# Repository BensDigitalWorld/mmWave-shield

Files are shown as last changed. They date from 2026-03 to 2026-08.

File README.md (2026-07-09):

<p align="center">
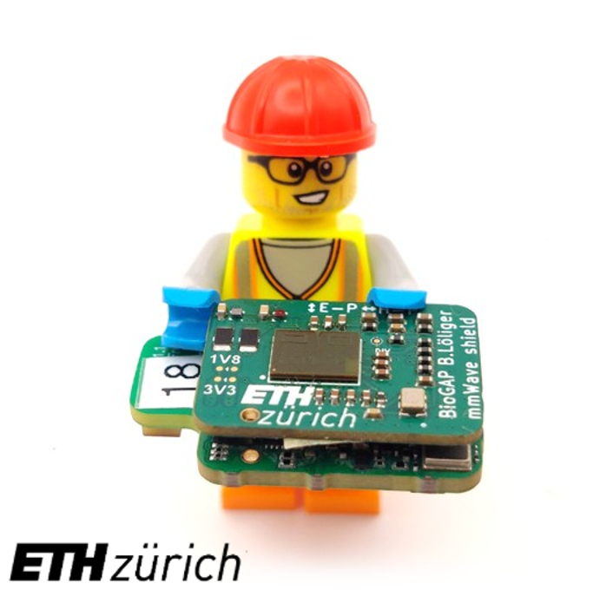
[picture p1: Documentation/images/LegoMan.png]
Device showcase
  
</p>

# mmWave-shield

## Wearable mmWave Sensor, for BP measurments. Shield for the BioGap9 Platform 

## Introduction

This repository contains the hardware, firmware, and software developed for a wearable mmWave radar sensing prototype based on the BioGAP platform.

The project integrates a custom BGT60TR13C mmWave radar shield with the BioGAP firmware and provides Python tools for data acquisition, live visualization, offline signal processing, and validation measurements.

The system was developed as a research prototype for contactless pulse-wave sensing using a wearable mmWave radar sensor.

<p align="center">
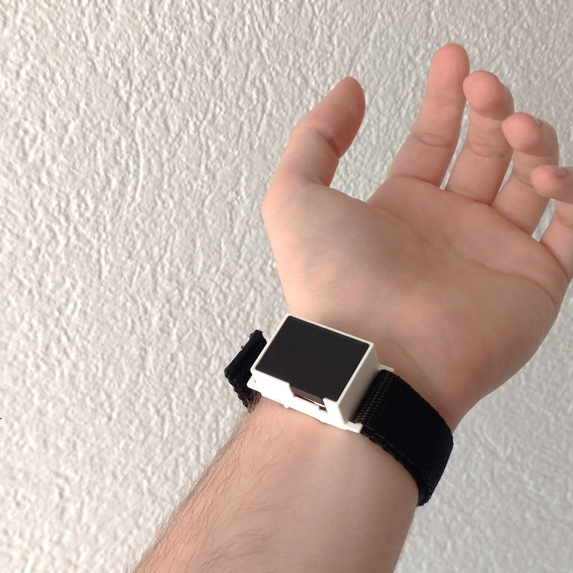
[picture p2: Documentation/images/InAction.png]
BioGAP mmWave radar system in action
  <br>
  <em>BioGAP mmWave radar system during validation measurements.</em>
</p>

The prototype includes the following main features:

- Custom mmWave radar shield based on the Infineon BGT60TR13C radar sensor
- Integration with the BioGAP wearable platform
- SPI-based radar control and raw frame readout
- BLE-based command interface and raw radar data streaming
- Python host software for acquisition, live viewing, and offline analysis
- Support for synchronized validation measurements with Finapres/NovaScope reference data
- Mechanical casing files for reproducing the validation setup

## Structure of the Repository

This repository is organized into the following main folders:

```text
Repository/
├── Documentation/
├── Firmware/
├── Hardware/
├── Software/
└── README.md
```

- `Documentation/` contains user documentation, setup instructions, and additional project notes and images.

- `Firmware/` contains the BioGAP firmware extension for the mmWave radar shield. This includes the mmWave application layer, radar control logic, BLE command integration, and firmware configuration changes.

- `Hardware/` contains the hardware design files for the custom mmWave radar shield and the mechanical casing files. This includes KiCad PCB files, fabrication outputs, casing STEP files, and Solid Edge source files.

- `Software/` contains the Python host software for acquisition, live visualization, signal processing, plotting, and validation analysis.

## Usage

For detailed setup and usage instructions, see 

[Getting started FW](Documentation/Firmware/getting_started.md)
[Getting started SW](Software/README.md)

A typical workflow consists of flashing the mmWave firmware, starting the Python host software, recording raw radar data, and processing the measurements offline.

<p align="center">
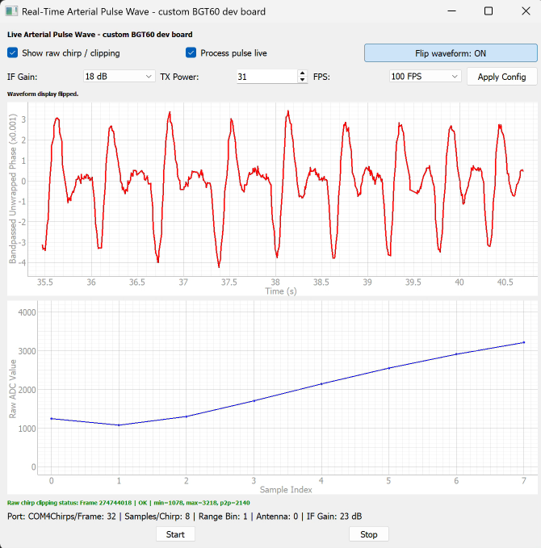
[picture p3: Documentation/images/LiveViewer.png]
mmWave live waveform viewer
  <br>
  <em>Python live viewer used to inspect the mmWave radar waveform in real time.</em>
</p>

## Authors

This project was developed at the Integrated Systems Laboratory (IIS) at ETH Zurich.

Main development:

- Benjamin Löliger, ETH Zurich  
  Hardware design, firmware integration, Python software, measurements, signal processing, documentation

Supervision and support:

- Sebastian Frey, ETH Zurich  
  Supervision and project guidance

- Andrea Cossettini, ETH Zurich  
  Supervision and project guidance

- Nima Bahmani, Aalton Finland  
  Supervision and project guidance

## License

The following parts of this repository are released under the Apache License 2.0:

- `Software/`
- `Firmware/`

See the corresponding license files for details: [Software/LICENSE](Software/LICENSE) and [Firmware/LICENSE](Firmware/LICENSE).

The hardware design files are released under the Solderpad Hardware License v0.51:

- `Hardware/`

See [Hardware/LICENSE](Hardware/LICENSE) for details.

This includes the PCB design files as well as the mechanical casing design files, such as STEP and Solid Edge files.

The following documentation images are released under the Creative Commons Attribution 4.0 International License (CC-BY-4.0):

- `Documentation/images/`
- `Hardware/casing/images/`

See the corresponding license files for details: [Documentation/images/LICENSE](Documentation/images/LICENSE) and [Hardware/Casing/images/LICENSE](Hardware/Casing/images/LICENSE).

Some files in the software tools directories contain third-party source code from the Infineon Radar SDK or files based on Infineon example code. Some of these files were adapted for this project.

See the respective source file headers for original copyright notices, modification notes, and license terms.

## Limitation of Liability

The hardware designs, firmware, and software in this repository are provided as-is, without warranty of any kind.

The project is a research prototype and is not intended for medical diagnosis, clinical decision-making, or safety-critical use. The authors and contributors are not liable for any damages or losses arising from the use of this repository, including but not limited to hardware damage, data loss, measurement errors, or incorrect interpretation of results.

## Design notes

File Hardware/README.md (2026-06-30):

# Hardware

## PCB

This directory contains the hardware design files for the custom mmWave radar shield used in this project.

The following PCB project is included:

```text
mmWave-shield-pcb/
```

The PCB was designed in KiCad and contains the schematic, PCB layout, local project libraries, and generated fabrication outputs required to manufacture and assemble the board.

Inside the project folder, you can find the KiCad design files as well as generated documentation and fabrication files such as schematics, bill of materials, Gerber files, and 3D model exports.

## Casing

In the folder Casing you can find .stl files for a 3d printed casing model that can be used with the BioGap + mmWave Shield. 

## License

The hardware source design files are licensed under the Solderpad Hardware License v0.51. See `Hardware/LICENSE` for details.

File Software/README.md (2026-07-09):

# Software

This folder contains the Python software used for acquiring, visualizing, processing, and plotting mmWave radar data from the BioGAP mmWave shield.

The software is organized around a reusable device communication class in `acquisition/bgt_com_class.py`. The other scripts use this class for live visualization, single recordings, FPS sweeps, and offline analysis.

## Getting Started

Create a local Python virtual environment inside the `Software/` folder:

```powershell
cd Software
python -m venv .venv
```

Activate the environment.

On Windows PowerShell:

```powershell
.\.venv\Scripts\Activate.ps1
```

Install the required Python packages:

```powershell
python -m pip install --upgrade pip
python -m pip install -r requirements.txt
```

### Optional: Infineon Radar SDK Python Wheel

Some scripts in `tools/devkit_exploration/` and `tools/static_distance_validation/` require the Infineon Radar SDK Python wrapper.

The Infineon Radar SDK wheel is not included in this repository and is not installed through `requirements.txt`. It has to be installed manually from the Infineon Radar SDK release package.

The required wheel can usually be found in the `python_wheels/` folder of the Infineon Radar SDK package. Choose the wheel that matches your operating system, CPU architecture, and Python version.

For example on windows: After creating and activating the Python virtual environment, install the wheel with:

```powershell
python -m pip install "path\to\radar_sdk\python_wheels\ifxradarsdk-3.6.4+4b4a6245-py3-none-win_amd64.whl"
```
Make sure that the wheel matches your operating system, CPU architecture, and Python version.

This is only required for scripts that directly use the Infineon DevKit or SDK-based processing examples. The BioGAP acquisition and plotting scripts do not require the SDK wheel unless they explicitly import `ifxradarsdk`.

## Measurement Data

Most scripts expect the measurement data to be available inside the `Software/data/` folder. The raw measurement data is not included in this repository because it can be large and may contain external measurement files.

If the measurement data is provided separately, for example via Dropbox, copy it into the `Software/` folder before running the analysis scripts.

Example structure:

```text
Software/
├── data/
│   ├── biogap_measurments/
│   │   └── radar_fps_sweep/
│   │       ├── radar_invivo_fps_sweep_2026-05-22_17-28/
│   │       ├── radar_invivo_fps_sweep_2026-05-22_17-51/
│   │       └── ...
│   │
│   ├── finaPress_measurments/
│   │   ├── 2026-05-22_19.24.20.nsc
│   │   ├── 2026-05-22_18.46.42.nsc
│   │   └── ...
│   │
│   ├── power_measurements/
│   │   └── powerLogs/
│   │       ├── Baseboard/
│   │       ├── shield3_3/
│   │       └── shield1_8/
│   │
│   └── processed/
│       ├── wrist/
│       └── temple/
```

The exact folder names should match the paths configured in the corresponding Python scripts.

The BioGAP acquisition and live-viewer scripts can be used without previously recorded data. However, the offline analysis and plotting scripts require the corresponding measurement files.

Scripts related to Finapres / maneuver analysis require both:

* the recorded mmWave radar data
* the corresponding Finapres / NovaScope `.nsc` files

Scripts related to power analysis require exported `.csv` logs recorded with the Nordic nRF Power Profiler Kit.

Some example data is provided and can be used in the jupyter notebook to get started with!

## Device Communication Class

The main interface to the BioGAP mmWave shield is implemented in:

```text
acquisition/bgt_com_class.py
```

The class wraps the communication with the BioGAP firmware and provides a Python interface for controlling the mmWave sensor and receiving radar frames.

Typical capabilities include:

* opening and closing the communication interface
* powering the mmWave shield on and off
* configuring the radar
* starting and stopping radar streaming
* setting radar parameters such as IF gain, TX power, and frame rate
* receiving raw radar frames
* optionally receiving frames in a background thread
* accessing either the next available frame or the most recent frame

The received raw radar frames are represented as NumPy arrays with the shape:

```text
(num_rx_antennas, num_chirps, num_samples)
```

For complete recordings, the resulting saved data usually has the shape:

```text
(num_frames, num_rx_antennas, num_chirps, num_samples)
```

## Usage

Scripts should be started as Python modules from inside the `Software/` folder. This keeps imports and relative data paths and imports consistent.

Example:

```powershell
python -m tools.static_distance_validation.static_distance_devkit
```

### Record some Data Example:

```powershell
python -m acquisition.record_fps_sweep_biogap
```

### Start the Live-Viewer:

```powershell
python -m live_viewer.live_waveform_viewer
```

### Run the Static Distance Validation:

```powershell
python -m tools.static_distance_validation.static_distance_biogap
```

### Analysis Examples:

Run the offline SNR analysis:

```powershell
python -m analysis_plotting.snr_analysis
```

Run the power analysis:

```powershell
python -m analysis_plotting.power_analysis
```

Most scripts contain configuration variables at the top of the file, such as input paths, output folders, recording names, frame rates, or selected measurement locations. These should be checked and adjusted before running the script.

## Notes

The scripts in `tools/devkit_exploration/` and `tools/static_distance_validation/` were mainly used during sensor bring-up and validation. They are useful for debugging and reference, but they are not the main BioGAP acquisition pipeline.

## License

Unless stated otherwise, the software in this folder is licensed under the Apache License 2.0. See `Software/LICENSE` file for details.

The `tools/devkit_exploration/` and `tools/static_distance_validation/third_party/` directories contain third-party sources from the Infineon Radar SDK or files based on Infineon example code. Some of these files were adapted for this project.

See the respective source file headers for the original copyright notices, modification notes, and license terms.

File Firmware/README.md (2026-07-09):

# mmWave Raw Data Stream

This folder contains the firmware to use the mmWave shield on BioGAP in streaming mode.

## Getting Started
If the SENSEI-SDK is not set up yet follow the steps in [../Documentation/Firmware/getting_started.md](../Documentation/Firmware/getting_started.md).

Make sure to attach the Mainboard to the mmWave shield.

1. Flash the NRF application by opening it in Visual Studio Code using the NRF Connect SDK extension.
```sh
cd src_NRF
west build -b nrf5340_senseiv1_cpuapp
west flash
```

Make sure your `SENSEI_SDK_ROOT` environment variable is set to the path of the SENSEI SDK.

## mmWave Firmware Extensions

This firmware is based on the existing BioGAP firmware and was extended to support the custom mmWave radar shield.

The following files and functions were added or modified for the mmWave integration.

### Added files

#### Device-tree and shield files

The following files define the custom mmWave shield and the BGT60TR13C device-tree binding.

These files need to be copied into the Sensei-SDK / firmware tree as described in [../Documentation/Firmware/getting_started.md](../Documentation/Firmware/getting_started.md).

```text
custom_dts/bgt60tr13c/
└── infineon,bgt60tr13c.yaml

custom_shields/mmWaveShield/
├── Kconfig.shield
├── mmWaveShield.defconfig
└── mmWaveShield.overlay
```

#### Radar register configuration files

The following files contain predefined BGT60TR13C register configurations for different radar settings. The base configuration is used for the main measurements, while the remaining files contain alternative or test configurations.

```text
src_NRF/sensors/mmwave/driver/
├── 100fps_32chirps_8samples_2000kHz.h
├── 200fps.h
├── 150fps.h
├── 100fps.h
├── 50fps.h
├── 25fps.h
└── static_distance.h
```

#### XENSIV BGT60TRxx driver files

The following files contain the general Infineon XENSIV BGT60TRxx radar driver used to communicate with the BGT60TR13C radar sensor.

```text
src_NRF/sensors/mmwave/driver/
├── xensiv_bgt60trxx_platform.h
├── xensiv_bgt60trxx_regs.h
├── xensiv_bgt60trxx.c
└── xensiv_bgt60trxx.h
```

#### mmWave application layer

The following files implement the project-specific mmWave application interface. They wrap the lower-level radar driver and provide the functions used by the rest of the firmware to power, configure, start, stop, and read out the radar sensor.

```text
src_NRF/sensors/mmwave/
├── mmWave_appl.c
└── mmWave_appl.h
```

#### Sensor stubs

A stub file was added to provide weak function definitions for unused sensors. This avoids compilation warnings or linker errors without requiring large changes to the existing BioGAP firmware structure.

```text
src_NRF/stubs/
└── sensor_stubs.c
```

### Modified files

The following existing firmware files were modified to integrate the mmWave radar sensor into the BioGAP firmware and to improve compatibility with different sensor configurations.

The build system and configuration files were extended to include the mmWave sensor code and to allow sensor modules to be enabled or disabled through configuration options. In main.c, only the required hardware initialization was added. Runtime control of the mmWave sensor is handled through tasks and BLE commands.

```text
src_NRF/
├── CMakeLists.txt
├── Kconfig
├── nrf5340_senseiv1_cpuapp.overlay
├── prj.conf
└── main.c
```
The BLE command interface was extended to support mmWave control commands and raw radar data streaming.

```text
src_NRF/ble/
├── ble_commands.h
└── ble_appl.c
```

The power-management code was adjusted for the mmWave shield.

```text
src_NRF/bsp/
├── pwr_bsp.c
├── battery/battery.c
└── power/power.c
```

A detailed overview of the modified existing files and code-level changes, excluding newly added files, is available in [../Documentation/Firmware/firmware_changes.md](../Documentation/Firmware/firmware_changes.md).

### Added mmWave Functions

The following functions were added to control the mmWave radar subsystem:

| Function | Description |
|---|---|
| `mmWave_HW_init()` | Initializes the BGT60TR13C hardware interface |
| `mmWave_power_on()` | Enables power to the mmWave shield |
| `mmWave_power_off()` | Disables power to the mmWave shield |
| `mmWave_configure()` | Configures the BGT60TR13C radar sensor |
| `mmWave_start_streaming()` | Starts raw radar data streaming |
| `mmWave_stop_streaming()` | Stops raw radar data streaming |
| `mmWave_set_ifGain()` | Changes the radar IF gain setting |
| `mmWave_set_txPower()` | Changes the radar TX power level |
| `mmWave_set_fps()` | Changes the radar frame rate |

### Data format

The firmware streams raw radar frames with the following logical structure:

```text
num_rx_antennas × num_chirps × num_samples
```

On the host side, the data is reconstructed into NumPy arrays with shape:

```text
num_frames × num_rx_antennas × num_chirps × num_samples
```

For the final measurement configuration, the typical frame format was:

```text
1 RX antenna × 32 chirps × 8 samples
```

The raw ADC samples are 12-bit values and are packed before BLE transmission to reduce the required data bandwidth.

## License

The files in the Firmware/ directory contain third-party sources that come with their own licenses. See the respective folders and source files' headers for the licenses used.

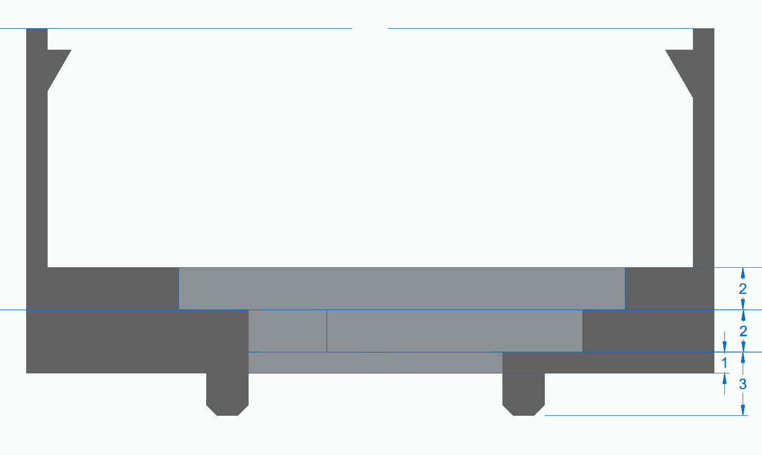
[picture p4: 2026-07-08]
Hardware/Casing/images/MeasurmentsSideView.png

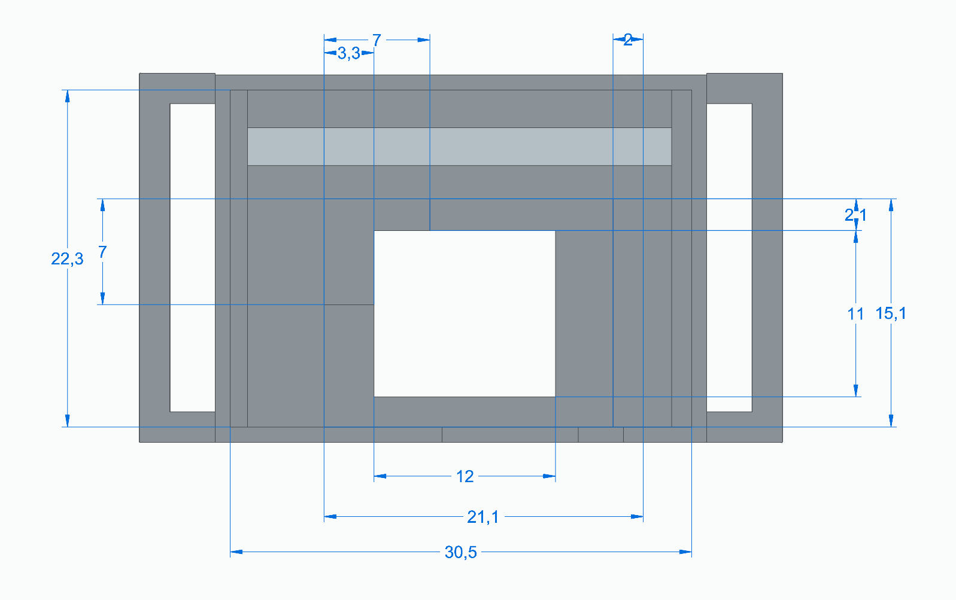
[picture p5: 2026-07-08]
Hardware/Casing/images/MeasurmentsTopView.png

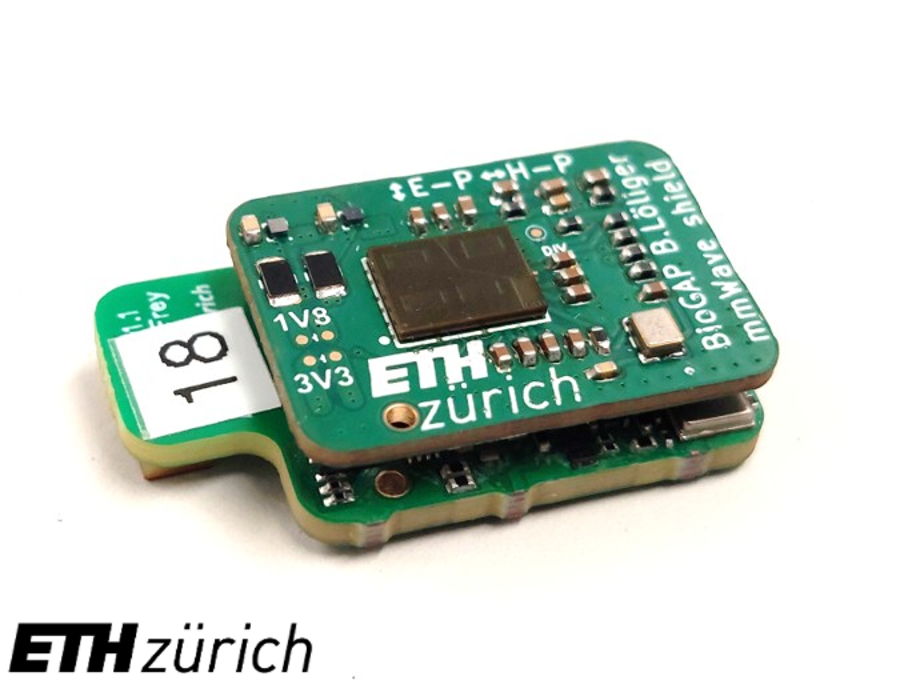
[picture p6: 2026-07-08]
Documentation/images/StackUp.png

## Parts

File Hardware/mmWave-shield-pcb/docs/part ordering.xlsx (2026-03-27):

Index | Quantity for one PCB | Manufacur part number | Description | Order number | Distributor
1 | 1 | BGT60TR13C | Infineon NFCW Radar Chip |  |  | 5
2 | 1 | KC2016K80.0000C1GE00 | 80Mhz Clk | 581-KC2016K80.0C1GE | Mouser
3 | 2 | TPS22916CYFPR | Power Switch ICs - Power Distribution 5.5-V 2-A 60-mohm 10 -nA leakage load A A 595-TPS22916CYFPT | 595-TPS22916CYFPR | Mouser
4 | 1 | DF40HC_3.0_-40DS-0.4V_51 | socket connector 40pin | 798-DF40HC3040DS04V5 | Mouser | CHECK HEIGHT BEFOR ORDERING
5 | 1 | DF40HC_3.0_-50DS-0.4V_51 | socket connector 50pin | 798-DF40HC3050DS04V | Mouser
6 | 2 | TLR2ATTD10L0F | Current Sense Resistors - SMD Metal Plate ChipType 10mOhm 1 Watt 1% | 660-TLR2ATTD10L0F | Mouser | EITHER/OR
7 | 2 | RC0805FR-070RL | Jumper -0Ohm Resistor 0805, 1%, 1/8W | 603-RC0805FR-070RL | Mouser
8 | 1 | RC0402FR-7D150RL | RES Thickfilm - SMD General Purpose Chip Resistor 0402, 150Ohms, 1%, 1/16W | 603-RC0402FR-7D150RL | Mouser
9 | 5 | MMZ1005B601CT000 | Ferrite Beads 600 OHM 25% 0.2A | 810-MMZ1005B601CT000 | Mouser
10 | 2 | MMZ1005S121CT000 | Ferrite Beads 120 OHM 25% 0.5A | 810-MMZ1005S121CT000 | Mouser
11 | 9 | CC0402KRX6S6BB105 | CAP CER 1uF 10V X6S 0402 10% | 603-CC0402KR6S6BB105 | Mouser
12 | 4 | 04026W106MAT2A | CAP cer 10uF 6.3V X6S 0402 20% | 581-04026W106MAT2A | Mouser
13 | 1 | CL05B103KB5NFNC | CAP cer 10nF 16V X7R 0402 10% | 187-CL05B103KB5NFNC | Mouser
14 | 1 | CL05B104KO5NNNC | CAP cer 100nF 16V X7R 0402 10% | 187-CL05B104KO5NNNC | Mouser
15 | 1 | GRT155C81C474KE01D | CAP cer 470nF 16V X6S 0402 10% | 81-GRT155C81C474KE1D | Mouser
16 | 2 | GRT155C81A475ME13J | Cap Cer 4.7uF 10V X6S 0402 20% | 81-GRT155C81A475ME3J | Mouser
17

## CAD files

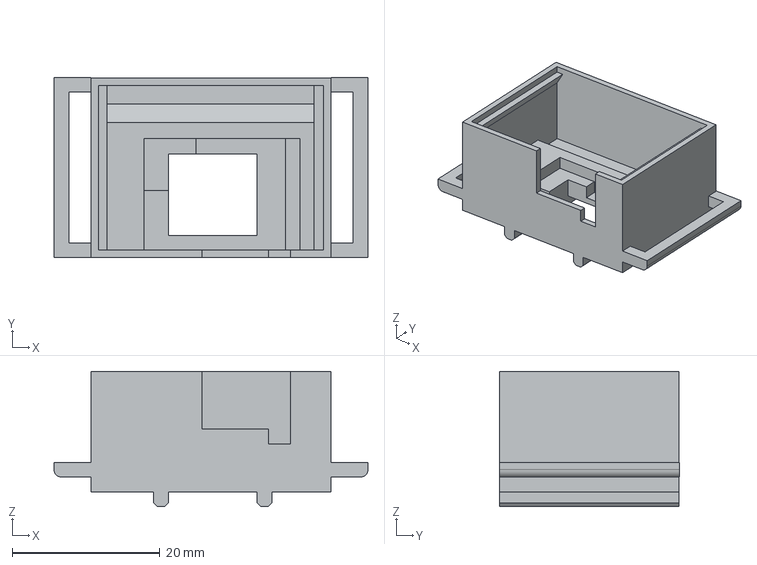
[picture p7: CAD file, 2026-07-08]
Hardware/Casing/Body.stp
42.5 x 24.4 x 18.3 mm

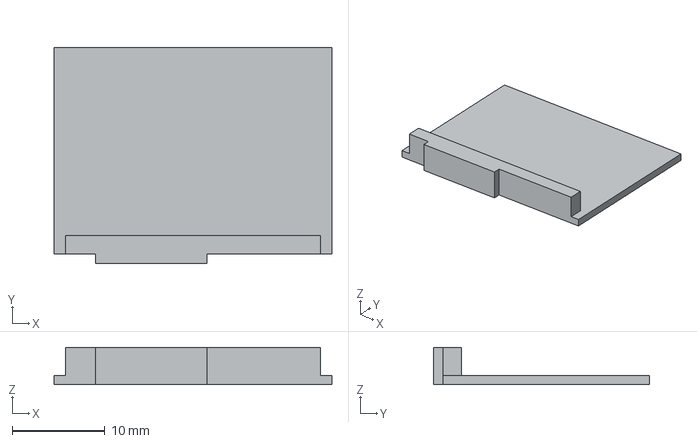
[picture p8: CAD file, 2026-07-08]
Hardware/Casing/Lid.stp
30.0 x 23.3 x 4.00 mm

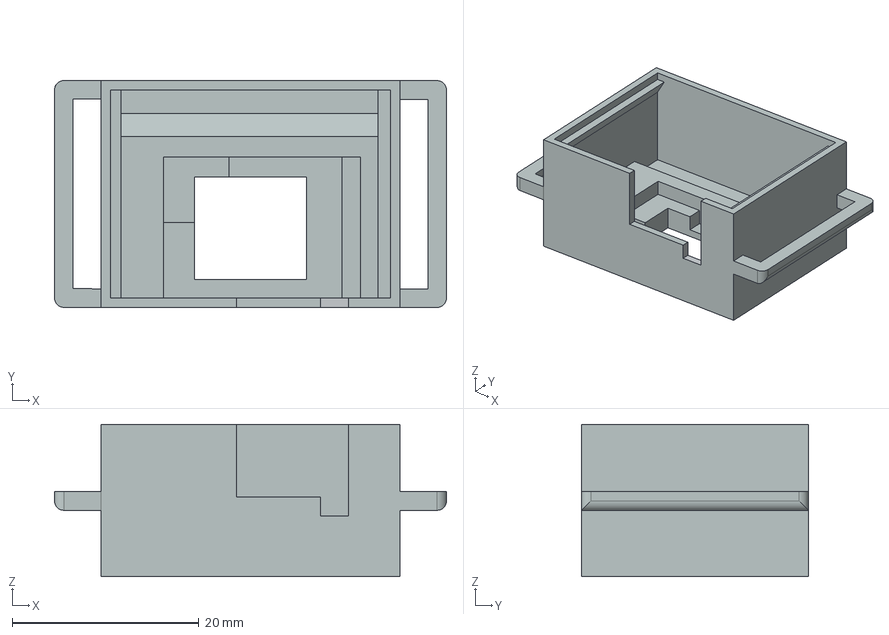
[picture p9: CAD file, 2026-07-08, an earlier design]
Hardware/Casing/old step files/Body_30mm_nofeet.stp
42.0 x 24.3 x 16.3 mm

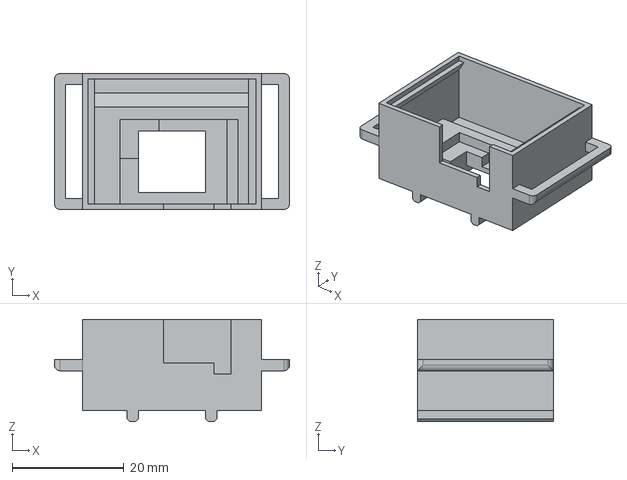
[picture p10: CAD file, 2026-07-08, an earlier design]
Hardware/Casing/old step files/Body_30mm.stp
42.0 x 24.3 x 18.3 mm

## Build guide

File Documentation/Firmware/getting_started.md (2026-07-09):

This document provides instruction on how to get started with the firmware, including building, flashing, and running the application on the nRF5340.

# Cloning the SENSEI-SDK

In order to build the firmware, you first need to clone the SENSEI-SDK repository, which contains the necessary Zephyr board support package and other dependencies.

```bash
git clone https://github.com/pulp-bio/sensei-sdk.git
```

Then move to the `sensei-sdk` folder:

```bash
cd sensei-sdk
```

Now you need to update the submodules to clone all the necessary third-party dependencies:

```bash
git submodule update --init --recursive
```

# Cloning the BioGAP FW Code
Now you need to clone the this repository, which contains the firmware source code and the custom modifications for the SENSEI-SDK for working with the mmWave Sensor.

```bash
git clone https://github.com/BensDigitalWorld/mmWave-shield.git
```

Then move to the `mmWave-shield` folder:

```bash
cd mmWave-shield
```

# Adapting the SENSEI-SDK for BioGAP

The cloned SENSEI-SDK is not ready to be used for the BioGAP firmware. For this reason, inside this repository, under `Firmware/` you will find two folders: 

- `custom_dts`: Contains a custom file for the Analog Front-End (AFE) and for the radar sensor (bgt60tr13c)
- `custom_shields`: Contains the custom shield definitions for the ExG (EEG/EMG), PPG and the mmWave sensors.

You need to copy the content of these two folders into the corresponding folders in the `sensei-sdk` repository.

First move to the mmWave-shield directory:

```bash
cd mmWave-shield
```

```bash
cp -r Firmware/custom_dts/* ~/sensei-sdk/NRF/dts/bindings
cp -r Firmware/custom_shields/* ~/sensei-sdk/NRF/boards/shields
```

This will copy the custom device tree source files and the custom shield definitions into the SENSEI-SDK, allowing you to build the firmware for the BioGAP hardware.

Additionally you have to do some modification to the `sensei-sdk/NRF/boards/arm/nrf5340_senseiv1/nrf5340_senseiv1_cpuapp.dts`.

First you need to comment the alias of the UART. The following snippet of code:
```
	aliases {
		i2ca = &i2c0;
		i2cb = &i2c1;
		uartgap = &uart_gap;
	};
```

Should become:
```
    aliases {
        i2ca = &i2c0;
        i2cb = &i2c1;
        // uartgap = &uart_gap;
    };
```

Then, just under the modification you need to add the following lines:

```
	buttons{
		gpio_lis2duxs12_int1: gpio_lis2duxs12_int1 {
			gpios = <&gpio0 23 GPIO_ACTIVE_HIGH>;
			label = "LIS2DUXS12_INT";
		};
		gpio_soft_rst: gpio_soft_rst {
			gpios = <&gpio0 26 GPIO_ACTIVE_HIGH>;
			label = "BUTTON_SOFT_INT";
		};
	};
```

So the final code should look something like this:

```
	aliases {
		i2ca = &i2c0;
		i2cb = &i2c1;
		// uartgap = &uart_gap;
	};
	buttons{
		gpio_lis2duxs12_int1: gpio_lis2duxs12_int1 {
			gpios = <&gpio0 23 GPIO_ACTIVE_HIGH>;
			label = "LIS2DUXS12_INT";
		};
		gpio_soft_rst: gpio_soft_rst {
			gpios = <&gpio0 26 GPIO_ACTIVE_HIGH>;
			label = "BUTTON_SOFT_INT";
		};
	};
```

Then you need to comment out the following lines:

```
	uart_gap_default: uart0_default {
		group1 {
			psels = <NRF_PSEL(UART_TX, 1, 0)>,
				<NRF_PSEL(UART_RX, 1, 1)>;
		};
	};

	uart_gap_sleep: uart0_sleep {
		group1 {
			psels = <NRF_PSEL(UART_TX, 1, 0)>,
				<NRF_PSEL(UART_RX, 1, 1)>;
			low-power-enable;
		};
	};
```

Finally, you also need to comment out these lines:

```
uart_gap: &uart3{
	status = "okay";
	current-speed = <115200>;

	pinctrl-0 = <&uart_gap_default>;
	pinctrl-1 = <&uart_gap_sleep>;
	pinctrl-names = "default", "sleep";
};
```
After these modifications, the SENSEI-SDK should be ready to be used for building the BioGAP firmware.

# Building the Firmware

Once everything is set up, you can build the firmware. The instruction are exactly the same as the one provided in the [SENSEI-SDK repository](https://github.com/pulp-bio/sensei-sdk).

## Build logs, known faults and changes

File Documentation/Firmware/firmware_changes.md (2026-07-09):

# Firmware Code-Level Changes

This document contains a code-level diff of the modified existing firmware files.

Newly added files are excluded from this comparison because they are documented separately in the firmware README.

```diff
diff --git a/Firmware/src_NRF/CMakeLists.txt b/Firmware/src_NRF/CMakeLists.txt
index b46a8d4..6f33bbf 100644
--- a/Firmware/src_NRF/CMakeLists.txt
+++ b/Firmware/src_NRF/CMakeLists.txt
@@ -4,7 +4,7 @@
 cmake_minimum_required(VERSION 3.20.0)
 
 # Enable shields
-set(SHIELD "SENSEI_ExGShield SENSEI_PPGShield")
+set(SHIELD "mmWaveShield")
 
 set(CONF_FILE prj.conf)
 set(OVERLAY_CONFIG "child_image/hci_ipc.conf")
@@ -22,7 +22,7 @@ list(APPEND EXTRA_ZEPHYR_MODULES
 
 # Configure the project
 find_package(Zephyr REQUIRED HINTS $ENV{ZEPHYR_BASE})
-project(exg_stream)
+project(mmWave_stream)

 target_sources(app PRIVATE
@@ -37,37 +37,82 @@ target_sources(app PRIVATE
     # BSP
     bsp/pwr_bsp.c
     bsp/battery/battery.c
-    bsp/power/power.c
     bsp/system_status/system_status.c
 
-    # AFE (Analog Front-End - ADS1298)
+
+)
+#depending on config includes: (Benis Changes)
+
+# AFE (Analog Front-End - ADS1298)
+if(CONFIG_SENSOR_EEG OR CONFIG_SENSOR_EMG)
+    target_sources(app PRIVATE
+    bsp/power/power.c
     afe/ads_appl.c
     afe/ads_spi_hw.c
     afe/ads_spi_comm.c
     afe/ads_spi_config.c
     afe/ads_spi_data.c
+    )
+endif()
 
-    # Sensors - IMU
+# Sensors - IMU
+if(CONFIG_SENSOR_IMU)
+    target_sources(app PRIVATE
     sensors/imu/imu_appl.c
     sensors/imu/lis2duxs12_sensor.c
     sensors/imu/driver/lis2duxs12_reg.c
+    )
+endif()
+
+# Sensors - Microphone
+if(CONFIG_SENSOR_MIC)
+    target_sources(app PRIVATE
+        sensors/mic/mic_appl.c
+    )
+endif()
+
+# Sensors - EEG
+if(CONFIG_SENSOR_EEG)
+    target_sources(app PRIVATE
+        sensors/eeg/eeg_appl.c
+    )
+endif()
 
-    # Sensors - Microphone
-    sensors/mic/mic_appl.c
+# Sensors - EMG
+if(CONFIG_SENSOR_EMG)
+    target_sources(app PRIVATE
+        sensors/emg/emg_appl.c
+    )
+endif()
 
-    # Sensors - PPG
-    sensors/ppg/ppg_appl.c
+# Sensors - PPG
+if(CONFIG_SENSOR_PPG)
+    target_sources(app PRIVATE
+        sensors/ppg/ppg_appl.c
+    )
+endif()
 
-    # Sensors - EEG
-    sensors/eeg/eeg_appl.c
+# Sensors - mmWave
+if(CONFIG_SENSOR_MMWAVE)
+    target_sources(app PRIVATE
+    sensors/mmWave/mmWave_appl.c
+    sensors/mmWave/driver/xensiv_bgt60trxx.c
+    )
+endif()
 
-    # Sensors - EMG
-    sensors/emg/emg_appl.c
+target_sources(app PRIVATE
+    
+    # Always include, only weak functions (Benis Change)
+    stubs/sensor_stubs.c
 
     # BLE
     ble/ble_appl.c
     ble/bluetooth.c
-)
+    )
+
+
 target_include_directories(app PRIVATE
     .
 )
+
+
diff --git a/Firmware/src_NRF/Kconfig b/Firmware/src_NRF/Kconfig
index e8dfcaa..e2f79b2 100644
--- a/Firmware/src_NRF/Kconfig
+++ b/Firmware/src_NRF/Kconfig
@@ -60,6 +60,35 @@ config SENSOR_EEG
 	  Enable support for EEG sensor. This will include the necessary drivers,
 	  state machine states, and data processing for EEG data acquisition.
 
+#my changes below, gotta adjust comments (Benis Changes)
+config SENSOR_PPG
+	bool "PPG sensor"
+	default n
+	help
+	  Enable support for EEG sensor. This will include the necessary drivers,
+	  state machine states, and data processing for EEG data acquisition.
+
+config SENSOR_IMU
+	bool "IMU sensor"
+	default n
+	help
+	  Enable support for EEG sensor. This will include the necessary drivers,
+	  state machine states, and data processing for EEG data acquisition.
+
+config SENSOR_MIC
+	bool "MIC sensor"
+	default n
+	help
+	  Enable support for EEG sensor. This will include the necessary drivers,
+	  state machine states, and data processing for EEG data acquisition.
+
+config SENSOR_MMWAVE
+	bool "mmWave sensor"
+	default n
+	help
+	  Enable support for EEG sensor. This will include the necessary drivers,
+	  state machine states, and data processing for EEG data acquisition.
+
 menu "State Machine Configuration"
 
 config STATE_MACHINE_USE_CPU_IDLE
diff --git a/Firmware/src_NRF/ble/ble_appl.c b/Firmware/src_NRF/ble/ble_appl.c
index f2ef477..aa17add 100644
--- a/Firmware/src_NRF/ble/ble_appl.c
+++ b/Firmware/src_NRF/ble/ble_appl.c
@@ -33,9 +33,11 @@
 #include "core/common.h"
 #include "core/sync_streaming.h"
 #include "sensors/eeg/eeg_appl.h"
+#include "sensors/emg/emg_appl.h"
 #include "sensors/imu/imu_appl.h"
 #include "sensors/imu/lis2duxs12_sensor.h"
 #include "sensors/mic/mic_appl.h"
+#include "sensors/mmWave/mmWave_appl.h"
 
 #include <zephyr/logging/log.h>
 #include <zephyr/logging/log_ctrl.h>
@@ -228,6 +230,7 @@ static void handle_ble_command(uint8_t cmd) {
     emg_stop_streaming();
     ble_print_packet_stats(); /* Print BLE packet stats */
     break;
+
   case START_MIC_STREAMING:
     LOG_INF("Ping START_MIC_STREAMING");
     mic_start_streaming();
@@ -245,6 +248,7 @@ static void handle_ble_command(uint8_t cmd) {
     mic_start_streaming();
     eeg_start_streaming();
     break;
+
   case STOP_EEG_MIC_STREAMING:
     LOG_DBG("Ping STOP_EEG_MIC_STREAMING");
     mic_stop_streaming();
@@ -252,6 +256,7 @@ static void handle_ble_command(uint8_t cmd) {
     ble_print_packet_stats(); /* Print BLE packet stats */
     sync_reset();             /* Clean up sync state */
     break;
+
   case START_STREAMING_ALL:
     LOG_DBG("Ping START_STREAMING_ALL");
     ble_reset_packet_counters(); /* Reset packet counters for new session */
@@ -260,6 +265,7 @@ static void handle_ble_command(uint8_t cmd) {
     eeg_start_streaming();
     imu_start_streaming();
     break;
+
   case STOP_STREAMING_ALL:
     LOG_DBG("Ping STOP_STREAMING_ALL");
     mic_stop_streaming();
@@ -268,14 +274,56 @@ static void handle_ble_command(uint8_t cmd) {
     ble_print_packet_stats(); /* Print BLE packet stats */
     sync_reset();             /* Clean up sync state */
     break;
+
   case START_IMU_STREAMING:
     LOG_DBG("Ping START_IMU_STREAMING");
     imu_start_streaming();
     break;
+    
   case STOP_IMU_STREAMING:
     LOG_DBG("Ping STOP_IMU_STREAMING");
     imu_stop_streaming();
     break;
+  
+  case START_MMWAVE_STREAMING:
+    LOG_DBG("Ping START_MMWAVE_STREAMING");
+    mmWave_start_streaming();
+    break;
+    
+  case STOP_MMWAVE_STREAMING:
+    LOG_DBG("Ping STOP_MMWAVE_STREAMING");
+    mmWave_stop_streaming();
+    break;
+
+  case CONFIGURE_MMWAVE:
+    LOG_DBG("Ping CONFIGURE_MMWAVE");
+    mmWave_configure();
+    break;
+
+  case TURN_OFF_MMWAVE:
+    LOG_DBG("Ping TURN_OFF_MMWAVE");
+    mmWave_power_off();
+    break;  
+    
+  case TURN_ON_MMWAVE:
+    LOG_DBG("Ping TURN_ON_MMWAVE");
+    mmWave_power_on();
+    break;
+  
+  case CHANGE_IFGAIN_MMWAVE:
+    LOG_DBG("Ping CONFIG_IFGAIN_MMWAVE");
+    mmWave_set_ifGain(ble_data_available.data[1]);
+    break;
+
+  case CHANGE_TXPOWER_MMWAVE:
+    LOG_DBG("Ping CONFIG_TXPOWER_MMWAVE");
+    mmWave_set_txPower(ble_data_available.data[1]);
+    break;
+
+  case CHANGE_FPS_MMWAVE:
+    LOG_DBG("Ping CONFIG_FPS_MMWAVE");
+    mmWave_set_fps(ble_data_available.data[1]);
+    break;
   }
 }
 
diff --git a/Firmware/src_NRF/ble/ble_commands.h b/Firmware/src_NRF/ble/ble_commands.h
index ee34519..27d7904 100644
--- a/Firmware/src_NRF/ble/ble_commands.h
+++ b/Firmware/src_NRF/ble/ble_commands.h
@@ -67,5 +67,13 @@
 #define SET_DEVICE_SETTINGS 12
 #define START_EMG_STREAMING 37
 #define STOP_EMG_STREAMING 38
+#define START_MMWAVE_STREAMING 39
+#define STOP_MMWAVE_STREAMING 40
+#define CONFIGURE_MMWAVE 41
+#define TURN_OFF_MMWAVE 42
+#define TURN_ON_MMWAVE 43
+#define CHANGE_IFGAIN_MMWAVE 44
+#define CHANGE_TXPOWER_MMWAVE 45
+#define CHANGE_FPS_MMWAVE 46
 
 #endif // BLE_COMMANDS_H
diff --git a/Firmware/src_NRF/bsp/battery/battery.c b/Firmware/src_NRF/bsp/battery/battery.c
index 9458a9b..78d5c78 100644
--- a/Firmware/src_NRF/bsp/battery/battery.c
+++ b/Firmware/src_NRF/bsp/battery/battery.c
@@ -41,7 +41,7 @@ static void battery_update_thread(void *arg1, void *arg2, void *arg3)
         k_sleep(K_MSEC(5000));
         // Only update if not currently reading ADS data to avoid I2C/SPI interference if shared
         if (ads_get_function() != ADS_READ) {
-            battery_update_status();
+            //battery_update_status();
         }
     }
 }
diff --git a/Firmware/src_NRF/bsp/power/power.c b/Firmware/src_NRF/bsp/power/power.c
index 05a8794..96d3aab 100644
--- a/Firmware/src_NRF/bsp/power/power.c
+++ b/Firmware/src_NRF/bsp/power/power.c
@@ -22,10 +22,14 @@
 
 LOG_MODULE_REGISTER(power_bsp, LOG_LEVEL_INF);
 
+#if defined(CONFIG_SENSOR_EEG) || defined(CONFIG_SENSOR_EMG)
 #define GPIO_NODE_ads1298_pwr DT_NODELABEL(gpio_ads1298_pwr)
 static const struct gpio_dt_spec gpio_p0_31_ads1298_pwr = GPIO_DT_SPEC_GET(GPIO_NODE_ads1298_pwr, gpios);
+#endif
 
 int power_init(void) {
+    #if defined(CONFIG_SENSOR_EEG) || defined(CONFIG_SENSOR_EMG)
+
     // Enable ADS1298 power GPIO
     if (!device_is_ready(gpio_p0_31_ads1298_pwr.port)) {
         LOG_ERR("ADS1298 power GPIO port not ready");
@@ -36,11 +40,13 @@ int power_init(void) {
         LOG_ERR("ADS pwr GPIO init error");
         return -1;
     }
-    
+    #endif
     LOG_INF("Power BSP initialized");
     return 0;
 }
 
+#if defined(CONFIG_SENSOR_EEG) || defined(CONFIG_SENSOR_EMG)
+
 int power_ads_off(void) {
     struct max77654_conf *pmic_conf = &pmic_h.conf;
 
@@ -120,6 +126,7 @@ int power_ads_on_bipolar(void) {
 
     return 0;
 }
+#endif
 
 int power_exg_on(void) {
 #if defined(CONFIG_SENSOR_EEG) && !defined(CONFIG_SENSOR_EMG)
diff --git a/Firmware/src_NRF/bsp/pwr_bsp.c b/Firmware/src_NRF/bsp/pwr_bsp.c
index 7118e0c..b1fca36 100644
--- a/Firmware/src_NRF/bsp/pwr_bsp.c
+++ b/Firmware/src_NRF/bsp/pwr_bsp.c
@@ -142,7 +142,7 @@ int pwr_bsp_start() {
   pmic_conf->sbb_conf[2].peak_current = MAX77654_SBB_PEAK_CURRENT_1A;
   pmic_conf->sbb_conf[2].active_discharge = false;
   pmic_conf->sbb_conf[2].en = MAX77654_REG_ON;
-  pmic_conf->sbb_conf[2].output_voltage_mV = 1200;
+  pmic_conf->sbb_conf[2].output_voltage_mV = 3300;
 
   pmic_conf->ldo_conf[0].mode = MAX77654_LDO_MODE_LDO;
   pmic_conf->ldo_conf[0].active_discharge = false;
diff --git a/Firmware/src_NRF/main.c b/Firmware/src_NRF/main.c
index 3d0f0d1..52b4403 100644
--- a/Firmware/src_NRF/main.c
+++ b/Firmware/src_NRF/main.c
@@ -53,6 +53,7 @@
 #include "sensors/imu/imu_appl.h"
 #include "sensors/mic/mic_appl.h"
 #include "sensors/eeg/eeg_appl.h"
+#include "sensors/mmWave/mmWave_appl.h"
 
 // Inter-board hardware synchronization
 #include "core/board_sync.h"
@@ -71,6 +72,7 @@ struct uart_data_t {
 };
 
 void z_fatal_error(unsigned int reason, const z_arch_esf_t *esf) {
+  volatile unsigned int r = reason;
   LOG_INF("Fatal error occurred: %d", reason);
   while (1) {
     // Halt here for debugging
@@ -105,6 +107,7 @@ int main(void) {
 
   LOG_INF("Enabling charge...");
   pwr_charge_enable();
+
   LOG_INF("Initializing ADS...");
   ret = ads_dr_init();
 
@@ -155,6 +158,17 @@ int main(void) {
   }
 #endif
 
+
+  // Initialize mmWave subsystem
+  LOG_INF("Initializing mmWave subsystem...");
+  if (mmWave_HW_init() != 0) {
+    LOG_WRN("mmWave initialization failed - mmWave streaming disabled");
+  } else {
+    LOG_INF("mmWave subsystem initialized");
+  }
+
+
+
   // Initialize inter-board synchronization
   LOG_INF("Initializing board sync...");
   if (board_sync_init() != 0) {
diff --git a/Firmware/src_NRF/nrf5340_senseiv1_cpuapp.overlay b/Firmware/src_NRF/nrf5340_senseiv1_cpuapp.overlay
index dfc5e6d..c8d1e1c 100644
--- a/Firmware/src_NRF/nrf5340_senseiv1_cpuapp.overlay
+++ b/Firmware/src_NRF/nrf5340_senseiv1_cpuapp.overlay
@@ -16,7 +16,7 @@
 &clock {
     hfclkaudio-frequency = <12288000>;
 };
-
+/*
 &pinctrl {
     pdm_default: pdm_default {
         group1 {
@@ -32,7 +32,7 @@ dmic_dev: &pdm0 {
     pinctrl-names = "default";
     clock-source = "ACLK";
 };
-
+*/
 // /*
 //  * Inter-board synchronization GPIO
 //  *
diff --git a/Firmware/src_NRF/prj.conf b/Firmware/src_NRF/prj.conf
index 34923b4..ed9d4c1 100755
--- a/Firmware/src_NRF/prj.conf
+++ b/Firmware/src_NRF/prj.conf
@@ -39,10 +39,12 @@ CONFIG_NFCT_PINS_AS_GPIOS=y
 
 # SPI Configuration
 CONFIG_NRFX_SPIM2=y
-# CONFIG_SPI=y
+CONFIG_SPI=y
 
 # Sensor Support
 CONFIG_SENSOR=y
+CONFIG_SENSOR_MMWAVE=y
+CONFIG_SENSOR_IMU=y
 
 #===============================================================================
 # Debug and Logging
```

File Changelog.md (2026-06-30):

# Changelog

## Version 1.0 (30.06.2026)
- Inital version

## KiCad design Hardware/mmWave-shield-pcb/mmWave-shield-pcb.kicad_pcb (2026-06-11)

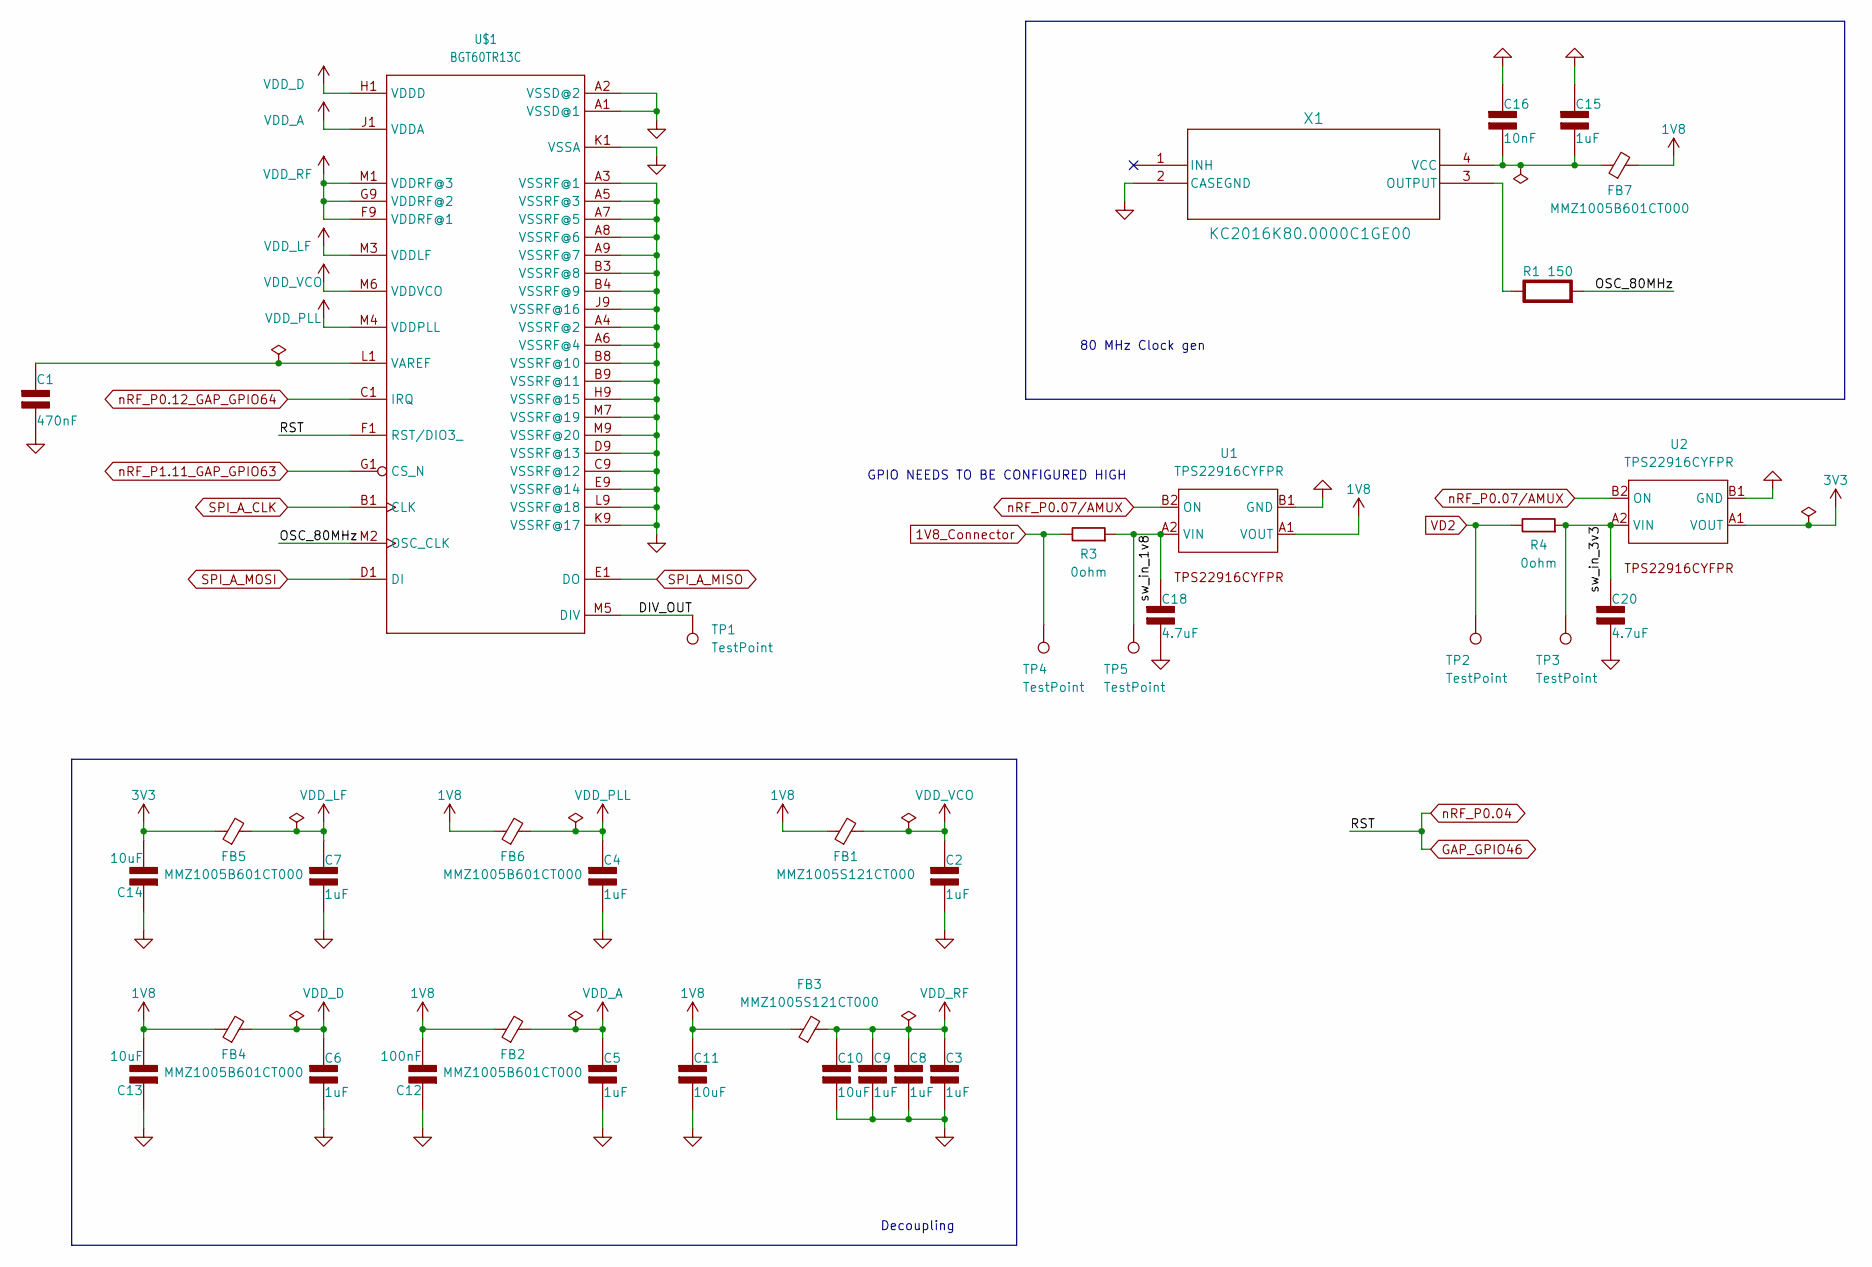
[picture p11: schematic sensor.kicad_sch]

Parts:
C1: 470nF; C_0402_1005Metric; Rating V
C2, C3, C4, C5, C6, C7, C8, C9, C15: 1uF; C_0402_1005Metric; Rating V
C10, C11, C13, C14: 10uF; C_0402_1005Metric; Rating V
C12: 100nF; C_0402_1005Metric; Rating V
C16: 10nF; C_0402_1005Metric; Rating V
C18, C20: 4.7uF; C_0402_1005Metric; Rating V
FB1, FB3: MMZ1005S121CT000; IND_1005_TDK-L
FB2, FB4, FB5, FB6, FB7: MMZ1005B601CT000; IND_1005_TDK-L
R1: 150; R_0402_1005Metric; Rating W
R3, R4: 0ohm; R_0805_2012Metric
TP1, TP2, TP3, TP4, TP5: TestPoint; TestPoint_Pad_D1.0mm
U1, U2: TPS22916CYFPR
U$1: BGT60TR13C; BGA40N50P9X12_500X650X90-V
X1: KC2016K80.0000C1GE00; KC2016K_KYO

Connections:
1V8: C11.1 (+), C12.2 (-), C13.2 (-), FB1.1, FB2.1, FB3.1, FB4.1, FB6.1, FB7.2, U1.A1 (VOUT)
1V8_Connector: R3.2, TP4.1; also elsewhere on the board
3V3: C14.2 (-), FB5.1, U2.A1 (VOUT)
/sensor/DIV_OUT: TP1.1, U$1.M5 (DIV); also elsewhere on the board
/sensor/OSC_80MHz: R1.2 (-), U$1.M2 (OSC_CLK)
/sensor/sw_in_1v8: C18.1 (+), R3.1, TP5.1, U1.A2 (VIN)
/sensor/sw_in_3v3: C20.1 (+), R4.1, TP3.1, U2.A2 (VIN)
GAP_GPIO46: U$1.F1 (RST/DIO3_); also elsewhere on the board
GND: C1.2 (-), C2.2 (-), C3.2 (-), C4.2 (-), C5.2 (-), C6.2 (-), C7.2 (-), C8.2 (-), C9.2 (-), C10.2 (-), C11.2 (-), C12.1 (+), C13.1 (+), C14.1 (+), C15.1 (+), C16.1 (+), C18.2 (-), C20.2 (-), U1.B1 (GND), U2.B1 (GND), U$1.A1 (VSSD@1), U$1.A2 (VSSD@2), U$1.A3 (VSSRF@1), U$1.A4 (VSSRF@2), U$1.A5 (VSSRF@3), U$1.A6 (VSSRF@4), U$1.A7 (VSSRF@5), U$1.A8 (VSSRF@6), U$1.A9 (VSSRF@7), U$1.B3 (VSSRF@8), U$1.B4 (VSSRF@9), U$1.B8 (VSSRF@10), U$1.B9 (VSSRF@11), U$1.C9 (VSSRF@12), U$1.D9 (VSSRF@13), U$1.E9 (VSSRF@14), U$1.H9 (VSSRF@15), U$1.J9 (VSSRF@16), U$1.K1 (VSSA), U$1.K9 (VSSRF@17), U$1.L9 (VSSRF@18), U$1.M7 (VSSRF@19), U$1.M9 (VSSRF@20), X1.2 (CASEGND); also elsewhere on the board
unnamed: C1.1 (+), U$1.L1 (VAREF)
unnamed: C15.2 (-), C16.2 (-), FB7.1, X1.4 (VCC)
unnamed: R1.1 (+), X1.3 (OUTPUT)
SPI_A_CLK: U$1.B1 (CLK); also elsewhere on the board
SPI_A_MISO: U$1.E1 (DO); also elsewhere on the board
SPI_A_MOSI: U$1.D1 (DI); also elsewhere on the board
VD2: R4.2, TP2.1; also elsewhere on the board
VDD_A: C5.1 (+), FB2.2, U$1.J1 (VDDA)
VDD_D: C6.1 (+), FB4.2, U$1.H1 (VDDD)
VDD_LF: C7.1 (+), FB5.2, U$1.M3 (VDDLF)
VDD_PLL: C4.1 (+), FB6.2, U$1.M4 (VDDPLL)
VDD_RF: C3.1 (+), C8.1 (+), C9.1 (+), C10.1 (+), FB3.2, U$1.F9 (VDDRF@1), U$1.G9 (VDDRF@2), U$1.M1 (VDDRF@3)
VDD_VCO: C2.1 (+), FB1.2, U$1.M6 (VDDVCO)
nRF_P0.07/AMUX: U1.B2 (ON), U2.B2 (ON); also elsewhere on the board
nRF_P0.12_GAP_GPIO64: U$1.C1 (IRQ); also elsewhere on the board
nRF_P1.11_GAP_GPIO63: U$1.G1 (CS_N); also elsewhere on the board

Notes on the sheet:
80 MHz Clock gen
GPIO NEEDS TO BE CONFIGURED HIGH
Decoupling

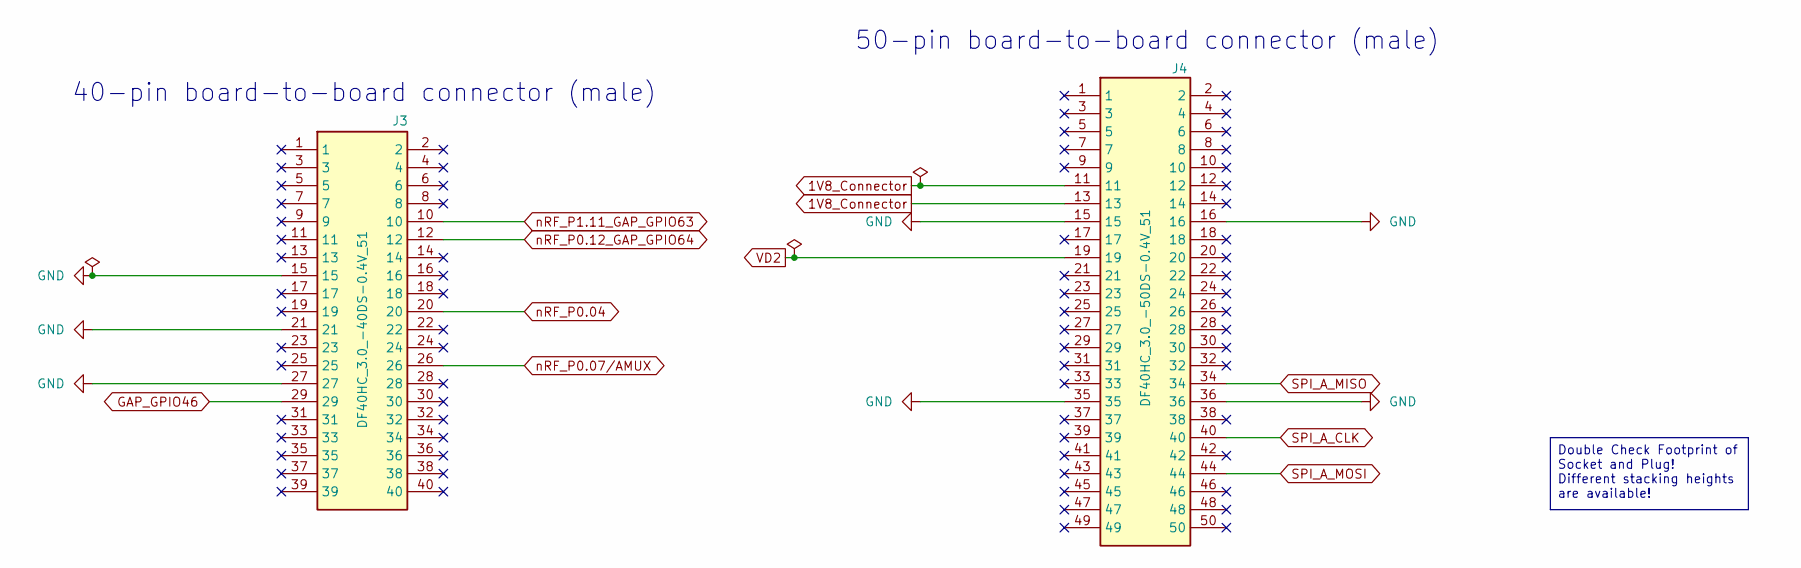
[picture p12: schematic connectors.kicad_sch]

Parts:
J3: DF40HC_3.0_-40DS-0.4V_51; Hirose_DF40HC(3.0)-40DS-0.4V_2x20_P0.4mm; Mouser Part Number 798-DF40HC3040DS04V5
J4: DF40HC_3.0_-50DS-0.4V_51; Hirose_DF40HC(3.0)-50DS-0.4V_2x25_P0.4mm; Mouser Part Number 798-DF40HC3050DS04V

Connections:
1V8_Connector: J4.11, J4.13; also elsewhere on the board
GAP_GPIO46: J3.20, J3.29; also elsewhere on the board
GND: J3.15, J3.21, J3.27, J4.15, J4.16, J4.35, J4.36; also elsewhere on the board
SPI_A_CLK: J4.40; also elsewhere on the board
SPI_A_MISO: J4.34; also elsewhere on the board
SPI_A_MOSI: J4.44; also elsewhere on the board
VD2: J4.19; also elsewhere on the board
nRF_P0.07/AMUX: J3.26; also elsewhere on the board
nRF_P0.12_GAP_GPIO64: J3.12; also elsewhere on the board
nRF_P1.11_GAP_GPIO63: J3.10; also elsewhere on the board

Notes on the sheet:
50-pin board-to-board connector (male)
40-pin board-to-board connector (male)
Double Check Footprint of Socket and Plug! Different stacking heights are available!

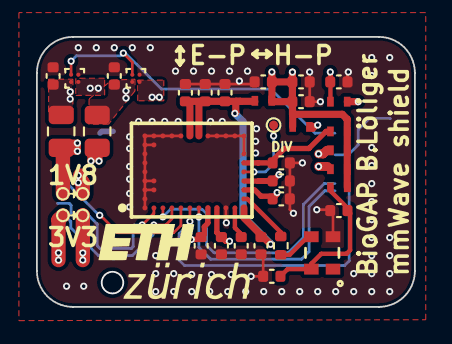
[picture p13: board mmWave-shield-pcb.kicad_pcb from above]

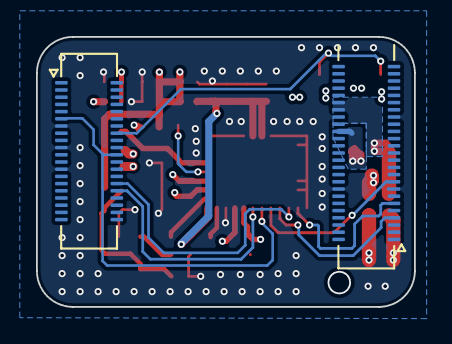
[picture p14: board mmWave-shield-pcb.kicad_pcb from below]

Board: 4 copper layers, 21.0 x 15.0 mm, 39 parts (2 on the bottom side), 25 nets.

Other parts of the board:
DIV: TestPoint; TestPoint_Pad_D1.0mm

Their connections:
/sensor/DIV_OUT: DIV.1; also elsewhere on the board

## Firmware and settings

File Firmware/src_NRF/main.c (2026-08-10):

/*
 * ----------------------------------------------------------------------
 *
 * File: main.c
 *
 * Copyright (C) 2024-2026 ETH Zurich and University of Bologna
 * Copyright (C) 2026 Benjamin Löliger
 *
 * Authors:
 * - Philip Wiese (wiesep@iis.ee.ethz.ch), ETH Zurich
 *
 * Modified by:
 * - Benjamin Löliger (bloeliger@ethz.ch)
 *
 * Modifications:
 * - Added mmWave HW init to the main init sequence
 *
 * ----------------------------------------------------------------------
 * SPDX-License-Identifier: Apache-2.0
 *
 * Licensed under the Apache License, Version 2.0 (the License); you may
 * not use this file except in compliance with the License.
 * You may obtain a copy of the License at
 *
 * www.apache.org/licenses/LICENSE-2.0
 *
 * Unless required by applicable law or agreed to in writing, software
 * distributed under the License is distributed on an AS IS BASIS, WITHOUT
 * WARRANTIES OR CONDITIONS OF ANY KIND, either express or implied.
 * See the License for the specific language governing permissions and
 * limitations under the License.
 */

#include <zephyr/bluetooth/bluetooth.h>
#include <zephyr/bluetooth/gatt.h>
#include <zephyr/bluetooth/hci.h>
#include <zephyr/bluetooth/uuid.h>
#include <zephyr/device.h>
#include <zephyr/devicetree.h>
#include <zephyr/drivers/gpio.h>
#include <zephyr/drivers/sensor.h>
#include <zephyr/drivers/uart.h>
#include <zephyr/kernel.h>
#include <zephyr/logging/log.h>
#include <zephyr/logging/log_ctrl.h>
#include <zephyr/sys/ring_buffer.h>
#include <zephyr/usb/usb_device.h>
#include <zephyr/usb/usbd.h>

#include "bsp/pwr_bsp.h"
#include "pwr/pwr.h"
#include "pwr/pwr_common.h"
#include "max77654.h"

#include "afe/ads_spi.h"
#include "ble/ble_appl.h"
#include "core/common.h"
#include "sensors/imu/imu_appl.h"
#include "sensors/mic/mic_appl.h"
#include "sensors/eeg/eeg_appl.h"
#include "sensors/mmWave/mmWave_appl.h"

// Inter-board hardware synchronization
#include "core/board_sync.h"

static const struct device *const uart_dev = DEVICE_DT_GET_ONE(zephyr_cdc_acm_uart);

LOG_MODULE_REGISTER(main, LOG_LEVEL_INF);

#define UART_BUF_SIZE 40
#define MINIMAL_STACK_SIZE 1024

struct uart_data_t {
  void *fifo_reserved;
  uint8_t data[UART_BUF_SIZE];
  uint16_t len;
};

void z_fatal_error(unsigned int reason, const z_arch_esf_t *esf) {
  volatile unsigned int r = reason;
  LOG_INF("Fatal error occurred: %d", reason);
  while (1) {
    // Halt here for debugging
  }
}

int main(void) {
  int ret = 0;

  LOG_INIT();

  LOG_INF("LED Test on %s", CONFIG_BOARD);


  if (pwr_init()) {
    LOG_ERR("PWR Init failed!");
  }
  // pwr_start();
  if (pwr_bsp_start()) {
    LOG_ERR("PWR BSP Start failed!");
  }

  if (!device_is_ready(uart_dev)) {
    LOG_ERR("CDC ACM device not ready");
    return 0;
  }

  if (usb_enable(NULL)) {
    return 0;
  }
  LOG_INF("USB enabled");

  LOG_INF("Enabling charge...");
  pwr_charge_enable();

  LOG_INF("Initializing ADS...");
  ret = ads_dr_init();

  LOG_INF("Initializing SPI...");
  init_spi();

  LOG_INF("Powering GAP9...");
  gap9_pwr(true);
  LOG_INF("GAP9 powered up");

  struct uart_data_t *buf = k_malloc(sizeof(*buf));
  LOG_INF("Starting BLE adverts...");
  start_bluetooth_adverts();

  // Initialize microphone
  LOG_INF("Initializing microphone...");
  if (mic_init() != 0) {
    LOG_WRN("Microphone initialization failed - mic streaming disabled");
  } else {
    LOG_INF("Microphone initialized");
  }

  // Initialize IMU (LIS2DUXS12 accelerometer)
  LOG_INF("Initializing IMU...");
  if (imu_init() != 0) {
    LOG_WRN("IMU initialization failed - IMU streaming disabled");
  } else {
    LOG_INF("IMU initialized");
  }

#if defined(CONFIG_SENSOR_EEG) && !defined(CONFIG_SENSOR_EMG)
  // Initialize EEG subsystem
  LOG_INF("Initializing EEG subsystem...");
  if (eeg_init() != 0) {
    LOG_WRN("EEG initialization failed - EEG streaming disabled");
  } else {
    LOG_INF("EEG subsystem initialized");
  }
#endif

#if defined(CONFIG_SENSOR_EMG) && !defined(CONFIG_SENSOR_EEG)
  // Initialize EMG subsystem
  LOG_INF("Initializing EMG subsystem...");
  if (emg_init() != 0) {
    LOG_WRN("EMG initialization failed - EMG streaming disabled");
  } else {
    LOG_INF("EMG subsystem initialized");
  }
#endif


  // Initialize mmWave subsystem
  LOG_INF("Initializing mmWave subsystem...");
  if (mmWave_HW_init() != 0) {
    LOG_WRN("mmWave initialization failed - mmWave streaming disabled");
  } else {
    LOG_INF("mmWave subsystem initialized");
  }



  // Initialize inter-board synchronization
  LOG_INF("Initializing board sync...");
  if (board_sync_init() != 0) {
    LOG_WRN("Board sync initialization failed - inter-board sync disabled");
  } else {
    LOG_INF("Board sync initialized");
  }

  while (1) {
    k_msleep(1000); // Main thread can sleep now, all the work is handeled by other threads
    if (flag_isr_soft_reset) {
      // Soft reset the device
      // Put PMIC into factory reset
      // do a nop in a busy for loop for 100ms to allow the PMIC to process the command
      volatile int i;
      for (i = 0; i < 10000000; i++) {
        __asm__ volatile("nop");
      }

      int ret = max77654_factory_ship_mode(&pmic_h);
      if (ret != 0) {
        LOG_ERR("Failed to soft reset PMIC (error %d)", ret);
      } else {
        LOG_INF("PMIC soft reset triggered");
      }
      flag_isr_soft_reset = 0;
      for (i = 0; i < 10000000; i++) {
        __asm__ volatile("nop");
      }
    }
  }
  return 0;
}

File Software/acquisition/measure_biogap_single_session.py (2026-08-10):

# -----------------------------------------------------------------------------
#
# File: measure_biogap_single_session.py
#
# Last edited: 14.07.2026
#
# Copyright (C) 2026 Benjamin Löliger
#
# Authors:
# - Benjamin Löliger (bloeliger@ethz.ch)
#
# -----------------------------------------------------------------------------
# SPDX-License-Identifier: Apache-2.0
#
# Licensed under the Apache License, Version 2.0 (the "License"); you may
# not use this file except in compliance with the License.
# You may obtain a copy of the License at
#
# https://www.apache.org/licenses/LICENSE-2.0
#
# Unless required by applicable law or agreed to in writing, software
# distributed under the License is distributed on an "AS IS" BASIS, WITHOUT
# WARRANTIES OR CONDITIONS OF ANY KIND, either express or implied.
# See the License for the specific language governing permissions and
# limitations under the License.
# -----------------------------------------------------------------------------

import numpy as np
import os
import time
from datetime import datetime

from acquisition.bgt_com_class import BGT60SensorThreaded


# ===========================================================================
# Make Folder
# ===========================================================================

timestamp = datetime.now().strftime("%Y-%m-%d_%H-%M")
output_folder_name = f"radar_and_finapress_session_{timestamp}"

output_folder = os.path.join("data", "biogap_measurments", output_folder_name)

if not os.path.exists(output_folder):
    os.makedirs(output_folder)
    print(f"📁 Ordner erstellt: {output_folder}")

# ===========================================================================
# TEST CONFIGS
# ===========================================================================

SERIAL_PORT = 'COM4'
RECORD_TIME_S = 30
NUM_RX_ANTENNAS = 1
if_gain_dB = 33
TX_POWER = 31
FPS = 100
CHIRPS = 32
SAMPLES = 8

# ===========================================================================
# HELPER
# ===========================================================================

def print_progress(current, total, width=30):
    progress = current / total
    filled = int(width * progress)

    bar = "#" * filled + "-" * (width - filled)
    percent = progress * 100

    print(f"\r[{bar}] {current}/{total} Frames ({percent:5.1f}%)", end="", flush=True)

# ===========================================================================
# MAIN
# ===========================================================================


if __name__ == '__main__':

    # PRE-ALLOCATION for more speeeed
    num_frames = int(FPS * RECORD_TIME_S)

    data_buffer = np.zeros((num_frames, NUM_RX_ANTENNAS, CHIRPS, SAMPLES), dtype=np.float32)
    time_stamps = np.zeros(num_frames , dtype=np.uint32)
    sensor = BGT60SensorThreaded(
                port= SERIAL_PORT,
                NUM_RX_ANTENNAS=NUM_RX_ANTENNAS,
                NUM_CHIRPS=CHIRPS,
                NUM_SAMPLES=SAMPLES)
    
    valid_frames = 0
    timeouts = 0


    print(f"Recording of {num_frames} frames started...")

    sensor.start(gain_db=if_gain_dB,tx_power=TX_POWER, fps=FPS)

    # Data collection
    start_t = time.time()
    try:
        while valid_frames < num_frames:
            time_stamp, sync_state, frame_content = sensor.get_next_frame() 
            if frame_content is None:
                dropped_frames += 1
                print("Kein gültiger Frame erhalten.")
                continue
            # frame_contents[0] the data of all RX-Antennas
            data_buffer[valid_frames] = frame_content
            time_stamps[valid_frames] = time_stamp
            valid_frames += 1
            print_progress(valid_frames,num_frames)

        print()

    except KeyboardInterrupt:
        pass
    
    finally:
        stop_t = time.time()

        sensor.stop()
        sensor.close()

        # Saving
        np.save(os.path.join(output_folder, "data.npy"), data_buffer)
        np.save(os.path.join(output_folder, "time_stamps.npy"), time_stamps)

        print(f"💾 Files Saved")
        print(f"Took time: {stop_t - start_t:.2f}s (Should be: {RECORD_TIME_S}s)")

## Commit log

2026-03-02 adding first folders
    [01_sensors.SchDoc, 02_power.SchDoc, 03_mcus.SchDoc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]
2026-03-15 kicad project inital version
    [DF40C-40DP.stp, DF40C-50DP.stp, DF40HC(3.0)-40DS-0.4V.stp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]
2026-03-15 arranged components on pcb
    [mmWave-Shield.kicad_pcb]
2026-03-16 ignore template folders
    [01_sensors.SchDoc, 02_power.SchDoc, 03_mcus.SchDoc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]
2026-03-16 working on scematic1
    [connectors.kicad_sch, mmWave-Shield.kicad_pcb, sensor.kicad_sch]
2026-03-17 Placed Connectors in hopefully right way
    [DF40C-40DS.stp, DF40C-50DS.stp, connectors.kicad_sch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]
2026-03-17 exported 3d model
    [mmWave-Shield.step]
2026-03-20 small changes scematic
    [sensor.kicad_sch]
2026-03-22 V1 of pcb layout
    [connectors.kicad_sch, mmWave-Shield.kicad_pcb, sensor.kicad_sch]
2026-03-23 added some docs fpr the pcb
    [bom.csv, designators.csv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]
2026-03-23 small adjustments
    [connectors.kicad_sch, mmWave-Shield.kicad_pcb, sensor.kicad_sch]
2026-03-23 finished adding power controll
    [mmWave-Shield.kicad_pcb, sensor.kicad_sch]
2026-03-24 Cleaning up a bit
    [bom.csv, designators.csv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]
2026-03-24 changed schema
    [sensor.kicad_sch]
2026-03-24 Removed cap and rerouted some power lines
    [mmWave-Shield.kicad_pcb]
2026-03-25 added 3d models for new components
    [KC2016K_KYO.step, TPS22916CYFPR.step, mmWave-Shield.kicad_pcb]
2026-03-25 updated BoM
2026-03-27 Final Touches and genertated fabrication files
    [mmWave-Shield-B_Cu.gbl, mmWave-Shield-B_Mask.gbs, mmWave-Shield-B_Paste.gbp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]
2026-03-27 added part ordering list
    [part ordering.xlsx]
2026-06-10 Uploaded FW, added getting started
    [DF40C-40DP.stp, DF40C-40DS.stp, DF40C-50DP.stp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]
2026-06-11 Finish up HW cleaning
    [DF40C-40DP.stp, DF40C-50DP.stp, DF40HC(3.0)-40DS-0.4V.stp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]
2026-07-08 added 3d files and images, improved readme
    [Body.stp, Body_30mm.stp, Body_30mm_nofeet.stp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]
